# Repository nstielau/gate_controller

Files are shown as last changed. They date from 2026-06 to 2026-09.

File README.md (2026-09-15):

# Gate Controller

Secure, timed gate control using a Seeed Studio XIAO ESP32-S3 running
CircuitPython and a Firebase web app.

The [Drawbridge mobile app](https://drawbridge-45487.firebaseapp.com) uses Google
sign-in to send timed MQTT holds: 1m, 15m, 1h, 6h, or End hold. Connection
secrets stay in Firebase; each user sees their assigned gates. See the
[web app guide](firebase/README.md) for access administration, testing,
and deployment. Use `make web-test-unit` for quick checks, `make web-test`
for the full local suite, and `make web-deploy` to test and deploy Firebase.
`make web-test-mqtt` checks the live broker on a synthetic topic.

Per-device MQTT credentials are a planned hardening step. See the
[per-device credentials plan](docs/per-device-mqtt-credentials.md).
Administrators can manage roles and per-device OTA targets through the profile
menu's **Administration** view. Nick is the initial owner. See
[OTA operations](docs/ota-operations.md) for opt-in enrollment, GitHub releases,
USB recovery, and the required bench verification before field use.

The XIAO ESP32S3 CircuitPython app provides Wi-Fi provisioning, MQTT, and
connection/hold indicators. See [circuitpython/README.md](circuitpython/README.md)
for setup, deployment, and hardware verification. Host dependencies are
managed with `uv`; use `make setup`, `make test`, and `make deploy` from the
repository root.

Install the repository checks once, then let pre-commit run them on each commit:

```sh
make precommit-install
make precommit       # run against every tracked file
```

The hooks detect private keys and likely secrets, validate JSON/XML, catch
merge conflicts and whitespace errors, and run Ruff linting/formatting. Use
`make lint` for the Python-only Ruff check. Secret files such as `.env` and
`emqxsl-ca.crt` are ignored by Git and excluded from scanning.

The current bench firmware holds D10/GPIO9 LOW at startup. A hold message raises
D10 steadily for the requested duration. D2/GPIO3 blinks four times per second
while holding and is otherwise off. D0/GPIO1 indicates Wi-Fi; D1/GPIO2 indicates
MQTT readiness. The onboard LED pulses every two seconds to show the loop is
running. Each external LED needs its own 1 kΩ series resistor and ground return.
The temporary startup check flashes all three external LEDs three times.
D9 is unused. The diagrams below predate the four-LED assignment; see
[firmware LED wiring](circuitpython/README.md) for the current pin roles.
See the [connection guide](docs/xiao-breadboard.svg) and the
[170-hole mini breadboard layout](docs/xiao-breadboard.md), including the
Fritzing project and exact hole assignments. The transistor collector
LED is a disconnected bench load; the prospective LiftMaster eyes interface
has not been validated. Current firmware ignores legacy MQTT blink commands.
The installed wiring is documented in [this field photo](docs/wiring-installed.jpg).

The LiftMaster controller's EXIT terminal pair and its current yellow/green
wiring are shown below. Use this as a visual record of the installation; it
does not establish the terminal's electrical interface or ratings.

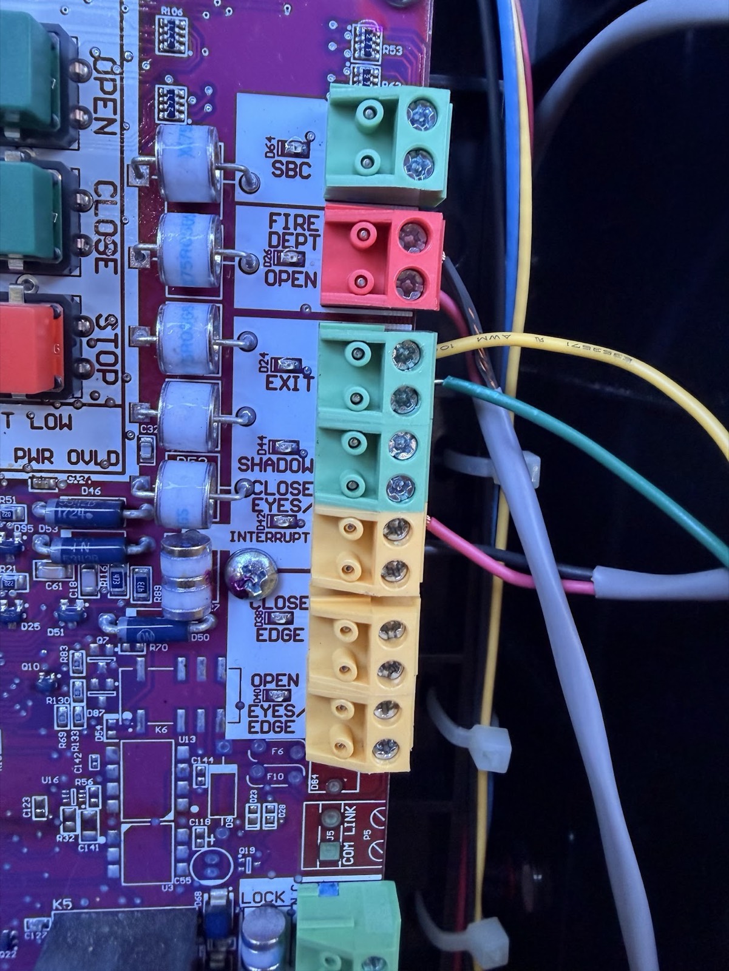
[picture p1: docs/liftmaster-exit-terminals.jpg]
LiftMaster EXIT terminal wiring


## Hardware

The current PCB is the [Drawbridge FeatherWing](hardware/featherwing/README.md),
50.8 × 22.86 mm, two layers, 1.6 mm thick. It fits above a Feather using underside
headers. J3 is a top-side 2.54 mm screw terminal for OUT_OC and GND, facing away
from USB. The transistor stage uses a 2N3904, 1 kΩ base resistor, and 100 kΩ
pulldown; each white/blue/green status LED has its own 1 kΩ resistor.

See [the generated BOM](hardware/featherwing/bom.csv) for exact parts and
[circuitpython/README.md](circuitpython/README.md) for the XIAO firmware wiring.
Older files at the root of `hardware/` are reference designs, not this board.

Commit all changes, then generate the fabrication package with `make featherwing-fab`.
The build requires a clean checkout; revisions use the first three HEAD characters,
and each ZIP records the full commit hash.
Use the freshly generated files in `artifacts/featherwing/`; the
[upload guide](hardware/featherwing/README.md#pcbway-upload) maps each file to its
PCBWay or Seeed upload field.

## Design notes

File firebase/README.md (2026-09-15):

# Drawbridge web app

Open [Drawbridge](https://drawbridge-45487.firebaseapp.com) and sign in with Google.
The `drawbridge.stielau.us` and `.web.app` aliases redirect to this canonical origin before initializing
authentication. Keep `web/origin.mjs` aligned with Google's OAuth redirect URI:
`https://drawbridge-45487.firebaseapp.com/__/auth/handler`. Firebase authorized
domains and Google OAuth redirect URIs are separate settings. Do not switch
`authDomain` to `.web.app` without first registering its callback with Google.
The mobile app offers **1 minute, 15 minutes, 60 minutes, 6 hours**, and
**End hold**. A six-hour hold asks for confirmation. Add it to your phone's
home screen for quick access.

The favicon uses `web/drawbridge-castle-128.png`, matching the header artwork.
Home-screen icons are checked-in exports in `web/icons/`; regenerate them with
`node tools/export_castle_icons.mjs` (requires the Playwright Chromium browser
installed by `make web-setup`). Regular builds only copy these files.

The centered loading indicator uses the original icon's pixels, with its bridge
rotating about the doorway hinge and suspension chains following the free edge.
`tools/build_loader_artwork.mjs` builds `web/drawbridge-loader.svg` from the
original icon and `web/drawbridge-loader-background.png` (an image-edited patch
visible only where the old bridge/chains were). Reduced-motion users see the
original still icon. Web builds regenerate, hash, and cache the loader asset.
`node tools/render_loader_gif.mjs` refreshes `artifacts/drawbridge-loader.gif`
with a complete four-second cycle at 50 fps and a live SVG preview at
`artifacts/drawbridge-loader.html`; this preview needs Playwright and ffmpeg.

To name a gate, select it and tap **Edit nickname**, enter a name, then tap
**Save nickname**. Names are shared with everyone assigned to that gate and
persist across visits. Any assigned user can rename an enabled gate. Names
must contain 1–80 characters; renaming does not send an MQTT command.

Only assigned users can control a gate. The browser receives gate IDs and
display names, never MQTT credentials or arbitrary broker/topic parameters.
The first assigned account is `nick.stielau@gmail.com`, for gate `b3640c`.

Administration has **Admins** and **Device Firmware** tabs and a refresh icon.
Firmware cards show the last reported app/base pair, separately from the assigned
target. Older boards show “Base not reported” until their USB bootstrap supports
independent reporting. See [OTA operations](../docs/ota-operations.md).

## Architecture and behavior

Firebase Hosting serves bundled HTML/JS/CSS. Google Authentication identifies
the user; reCAPTCHA Enterprise App Check protects all callable functions.
`listDevices` returns assigned, enabled gates. `holdGate` checks verified Google
sign-in, the current device allowlist, enabled state, exact topic, approved
duration, UUID request ID, and request age (60 seconds; 10 seconds of future
clock tolerance). CORS allows the two Drawbridge Hosting domains.

Accepted timed holds are counted server-side in each device record as
`holdCount` and shown as a small “holds issued” metric in the web app. End-hold
commands and uncertain deliveries do not increment the count.

Firestore transactions reserve commands before publishing, enforce a
three-second per-device cooldown, and prevent a repeated request ID from
publishing again. A changed payload with the same ID is rejected. Commands
are stored in `commands/<sha256(uid:requestId)>` with operator UID, device,
duration, timestamps, and `pending`, `accepted`, or `unknown` status. Keep these
records for audit; automated record deletion is not configured.

The function uses the existing EMQX broker over verified TLS on port 8883,
with the CA and credentials in Secret Manager. It publishes QoS 1 with
`retain=false`, using the existing firmware schema:

```json
{"version":1,"type":"hold_gate","duration_seconds":60,"command_id":"64-character-request-hash"}
```

Zero ends a hold. The XIAO starts timing when it receives the command. A new
command replaces the previous duration; it does not add to it.

**Accepted means MQTT PUBACK, not confirmation that the board received the
command or that the gate moved.** There is no physical gate-position feedback.
A disconnect, timeout, or ambiguous audit update reports uncertain delivery.
The app never queues offline commands or automatically retries a hold.
Request deduplication prevents repeated HTTP requests from publishing twice;
MQTT QoS 1 itself does not guarantee exactly-once hardware execution.

When a hold is accepted, Drawbridge stores its expected start and duration on
the gate record. The matching duration button displays a countdown and an
elapsed left-to-right color sweep. It survives refreshes and is shared with
other authorized users. It is an expected countdown only: direct MQTT commands,
lost board connectivity, or a command accepted by the broker but not delivered
to the board can make it disagree with physical gate state. An uncertain web
command clears the displayed expected hold rather than showing stale progress.

The app shell is cached with content-hashed assets and a content-based service
worker release. HTML and the service worker revalidate; hashed assets use
immutable caching. Updates offer a reload button. Authentication helpers,
API responses, external resources, and POST requests are never cached by the
service worker. An offline launch can display the shell, but sign-in and
commands still require connectivity. A first command after idle may take a
few seconds because functions scale to zero.

## Local setup and commands

Use Node/npm, Firebase CLI (tested with 15.30.0), gcloud, Java 21+, and the
repository's uv-managed Python environment. `make web-setup` installs a pinned
local Node 22 runtime, matching deployed functions, plus browser test binaries.
Keep both npm lockfiles committed. The UUID override patches a transitive
Google SDK dependency; review it with future SDK updates.

```sh
make setup
make web-setup
make web-build
make web-test-unit       # fast, offline validation + MQTT transport failure tests
make web-test-browser    # mobile Chromium and WebKit with a test gateway
make web-test-emulator   # actual Firestore transactions and deny-all client rules
make web-test           # all three
make web-test-mqtt      # live broker, three synthetic-topic cycles; no gate actuation
make web-test-live      # deployed OAuth redirect and unauthenticated API rejection
make web-deploy         # full web tests, then Functions + Hosting + rules
make web-status
```

The emulator target uses `demo-drawbridge` and refuses non-local Firestore
hosts. On macOS it checks Java via the Homebrew path; override
`JAVA_BIN=/path/to/java/bin` on other installations. These tests never publish
to the real gate. Existing `make test` and `make deploy` still test/deploy the
CircuitPython firmware independently.

The browser tests use a separate build in `artifacts/web-test`. Production
builds always use the real Firebase gateway and require both ignored public
config files. Never deploy the test build. Production output is `web/dist`.

### Public configuration on another checkout

Project: `drawbridge-45487`; region: `us-east1`; web app:
`1:498911170567:web:67d0d78cf97be687c85aa2`.

`.firebaserc` selects this project. Do not run `firebase init` over the existing
configuration. Copy `web/firebase-config.example.js` to
`web/firebase-config.js` and populate it from:

```sh
firebase apps:sdkconfig WEB 1:498911170567:web:67d0d78cf97be687c85aa2 --project drawbridge-45487
.venv/bin/python tools/firebase_cloud.py appcheck
```

The App Check helper reuses the Drawbridge reCAPTCHA key, registers the two
production domains, and writes `web/app-check-config.js`. Both configs contain
public identifiers, not authorization credentials, and are ignored locally.
No debug-token bypass is included in the production app.

### Access and device administration

Gate-access helpers use your gcloud login as `nick.stielau@gmail.com` and
project IAM. The profile dropdown also exposes **Administration** to server-verified
administrators. That view manages admin email assignments and per-device firmware
targets, separately from gate-control UID allowlists. `make admin-seed` initializes
Nick's protected owner record. All browser admin calls require verified Google
sign-in, App Check, and transactional role checks. See
[OTA operations](../docs/ota-operations.md) for release publishing, enrollment,
private artifact storage, and USB recovery.

```sh
make web-grant EMAIL=person@example.com DEVICE_ID=b3640c
make web-revoke EMAIL=person@example.com DEVICE_ID=b3640c
node_modules/.bin/node firebase/functions/admin.cjs disable nick.stielau@gmail.com b3640c
node_modules/.bin/node firebase/functions/admin.cjs enable nick.stielau@gmail.com b3640c
```

Grant reserves a Firebase user UID if that email has not signed in yet.
The user must still complete verified Google sign-in. Existing device access
lists are updated without replacing other users. Newly created device
documents default to enabled with the canonical command topic. Revoking
access or disabling a device blocks future commands; it does not cancel an
already-running hold. Sign in and select **Refresh access** after assignment.

Device documents live at `devices/<device-id>`:

```json
{
  "name": "Driveway gate",
  "enabled": true,
  "commandTopic": "gate/v1/devices/b3640c/command",
  "allowedUsers": ["firebase-auth-uid"]
}
```

Change the display name in the app with **Edit nickname**, or in the Firestore
console. The `renameGate` callable checks access transactionally and updates
only `name`; it cannot change device IDs, topics, permissions, or enabled state.
Access is by UID, not email.
Assign additional device IDs to different users with the same helper. This
release supports multiple devices on the existing broker; additional brokers
require server configuration and additional Secret Manager bindings.

### Secrets and deployment

```sh
make web-secrets
make web-deploy
```

The secret helper reads `MQTT_USERNAME` and `MQTT_PASSWORD` from ignored `.env`
and PEM data from ignored `emqxsl-ca.crt`. It uploads only changed values, without
printing them. Redeploy functions after rotation. Old secret versions remain;
disable superseded versions after confirming the new deployment works.

Runtime identity: `drawbridge-functions@drawbridge-45487.iam.gserviceaccount.com`.
It needs `roles/datastore.user` on the project and Secret Accessor on the three
MQTT secrets (the Firebase deploy command grants secret access). It does not
need project Editor. Functions use 256 MiB, zero minimum instances, two maximum
instances each, and a 30-second timeout. Function build images are cleaned up
after seven days. Blaze billing is enabled; no paid minimum instances are used.

## Verification and remaining manual checks

Automated coverage includes unauthenticated and non-Google rejection,
unassigned/disabled/missing devices, topic tampering, every duration, stale
requests, duplicate and concurrent requests, rate limiting, audit outcomes,
TLS options, timeout/error cleanup, mobile layout, sign-out, and offline
controls. The live MQTT smoke check verifies the real CA/credentials and
three publish/receive cycles on a unique `web-test-...` device topic.

Cached offline launch is automated in Chromium. The WebKit version of that
one test is explicitly skipped because Playwright's service-worker support
is Chromium-only; offline controls still run in both browsers. See
[Playwright service workers](https://playwright.dev/docs/service-workers).
Verify home-screen launch, Google redirect sign-in, and offline relaunch on
a real iPhone. Test a real hold only when gate actuation is intended, then use
End hold and check the board logs. Mock browser tests and synthetic MQTT
cycles do not prove a physical gate action.

For deployment checks, open the production app, confirm Google sign-in,
check that your assigned gate appears, and verify signed-out API requests
are rejected. First sign-in is an interactive step the CLI cannot complete
for you. The app deliberately does not claim a gate is open based solely on
broker acceptance.

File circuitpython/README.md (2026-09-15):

# XIAO ESP32S3 CircuitPython app

Wi-Fi provisioning, MQTT over verified TLS, and separate connection/hold
indicators. Targets CircuitPython 10.x; tested on 10.3.0.

| Output | Behavior |
| --- | --- |
| Onboard yellow LED | Running heartbeat: two 100 ms flashes, starting 250 ms apart, every 2 seconds (1.0.1). |
| D0 / GPIO1 external LED | Wi-Fi: 500 ms transitions while connecting; steady ON when connected. |
| D1 / GPIO2 external LED | MQTT: OFF without Wi-Fi; 500 ms transitions while connecting; steady ON after subscription. |
| D2 / GPIO3 external LED | Hold: OFF normally; four full blinks per second while D10 is HIGH. |
| D10 / GPIO9 transistor control | LOW at boot; HIGH only for the requested hold duration. |

D9 is reserved for optional OTA maintenance recovery. A hold command raises D10 steadily for its duration.
The D2 LED reports the commanded transistor state, not sensed gate position.
The temporary startup diagnostic flashes D0/D1/D2 together three times,
then releases the pins before normal operation. Its function and call are
marked for later removal.

Wire each of **D0, D1, D2 → its own 1 kΩ resistor → LED anode (+);
LED cathode (−) → XIAO GND**. D2/GPIO3 is a strapping pin; do not add a
pull-up or externally drive it during reset.
The [connection guide](../docs/xiao-breadboard.svg) predates this four-LED assignment.
D0 and D10 are board
labels: **D0 is GPIO1**, and **D10 is GPIO9**. The red charging LED is separate.

The onboard LED is active low; external LEDs are active high.
D2 uses 125 ms transitions, giving four complete on/off cycles per second.
All LED timers are independent of D10. Blocking Wi-Fi/TLS operations can briefly
pause blinking, especially during connection attempts.

## Setup and deployment

From the repository root, use **uv** (Python 3.11+):

```sh
make setup
make test
make deploy
```

Host dependencies are locked in `tools/requirements-dev.lock`. Refresh after
changing dependencies with:

```sh
uv pip compile tools/requirements-dev.txt -o tools/requirements-dev.lock
```

Put the downloaded CA at ignored `emqxsl-ca.crt` and credentials in ignored
`.env`:

```dotenv
MQTT_USERNAME=your-device-username
MQTT_PASSWORD='your-device-password'  # pragma: allowlist secret
```

Deployment copies the CA to `/certs/emqxsl-ca.crt` and renders only MQTT
username/password into device `settings.toml`, readable over USB. REST API
credentials stay on the host. The dotenv parser accepts literal quoted or
unquoted values; the last duplicate wins and process environment overrides
the file.

`make deploy` runs tests, preflights inputs, then copies changed app/library
files to `/Volumes/CIRCUITPY`, preserving unrelated files and settings.
Override with `CIRCUITPY=/path`. Filesystem writes normally trigger Python
autoreload; network recovery never deliberately hard-resets the board.

With missing settings, join the open `Gate-Setup-<chip suffix>` network and
visit `http://192.168.4.1`. The portal stores settings in NVM; deploy-time MQTT
credentials override saved credentials. Provisioned devices retry in station
mode after connection failures instead of reopening the portal.

## MQTT status

Default topics are `gate/v1/devices/<device-id>/command` and `/status`.
The ID is the lowercase chip suffix (`b3640c` for this board). The portal
can configure custom topics.

The device publishes retained `device_status` at connection and every ten
seconds with `boot_id`, `uptime_ms`, IP, and an `indicators` object containing
`wifi_connected`, `mqtt_connected` (both Wi-Fi and MQTT ready), `transistor_high`,
`wifi_led_on`, `mqtt_led_on`, `onboard_led_on`, `alive_edge_count`,
`hold_led_on`, and `hold_edge_count`.
Its last will reports `state: "offline"`.

The command schema is `{"version":1,"type":"hold_gate","duration_seconds":5,
"command_id":"unique-id"}`. Duration is 0–86400 seconds; zero cancels.
Commands are never retained, so a reboot cannot replay a timed gate action.
The firmware also rejects retained hold deliveries, including stale retained
messages left by older publishers.
Use `make hold DURATION=5` or `tools/mqtt_hold.py`. Invalid legacy blink
commands are rejected and cannot change either output.

## Verification

```sh
make test                   # offline regression suite
make test-hardware-smoke    # passive 20-second observation
make test-hardware          # passive 70-second observation
```

Host tests cover connection/hold LED independence, timed hold expiry, active-low polarity,
D0/D1/D2/D10 allocation and shutdown, legacy-command rejection, MiniMQTT handling,
configuration migration, portal parsing, publisher, and deployment behavior.

The live test requires a provisioned board connected over USB with working
Wi-Fi/MQTT. It waits up to 40 seconds for an online heartbeat, then checks
steady D0/D1 ON, advancing onboard heartbeat edge counts, and stable session logs. Hold activation should be tested
with `make hold DURATION=3` while watching the console. It fails on session/boot changes,
serial loss, missing heartbeats, or tracebacks. It never sends a command or
resets the board. The full run observes beyond the MQTT keepalive interval;
use it after firmware, timing, network, or library changes.

```sh
make test-hardware TEST_ARGS='--duration 120'
```

Raw logs and a JSON summary are saved to ignored `artifacts/indicators.*`.
These are software GPIO measurements; confirm physical light output visually.
Inactive-hold and disconnected behavior are covered by host tests; the live
indicator check does not activate the gate by itself.
The former MQTT command-cycle test does not apply to these automatic LEDs.

## Console

```sh
make console CONSOLE_WAIT=20
make console CONSOLE_WAIT=20 CONSOLE_ARGS=--reload
```

Default monitoring is passive; `--reload` intentionally restarts Python.
Use one serial reader at a time. With multiple boards, supply
`CONSOLE_ARGS='--port /dev/cu.usbmodem...'` or the live test's `--port` option.

The collector-powered LED in the diagram is a disconnected bench load.
The separate signal LEDs stay on the XIAO side. The prospective LiftMaster “eyes”
connection has not been established as a compatible gate-control interface.

## Opt-in OTA application updates

`drawbridge.py` contains the versioned application policy; `code.py` retains
networking and physical output leases. `boot.py`, the loader, libraries, and
the root recovery app are deployed over USB. OTA writes verified application
slots under `/ota/` and uses a trial boot before confirmation. Updates are
initially disabled. Two installations, hold deferral, and failure rollback have
passed on the bench; [the validation record](../docs/ota-bench-validation.md)
tracks remaining recovery and power-loss checks.
See [OTA operations](../docs/ota-operations.md) before enabling a device.
D9/GPIO8 is reserved as the active-low maintenance input during reset when
OTA is enabled on the XIAO. All other current pin roles are preserved.

The base and OTA app have independent versions. `lib/gate_base.py` defines the
USB bundle's `BASE_VERSION`; the selected application's `APP_VERSION` can move
forward independently. MQTT/Firebase report both, and Administration displays
the pair. Older boards show “Base not reported” until deliberately updated by
USB. Protected base commits require a version bump and change note; see the
OTA editing boundary in [AGENTS.md](../AGENTS.md).

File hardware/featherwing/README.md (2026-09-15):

# Drawbridge FeatherWing fabrication package

This is a revision-stamped prototype board for a Feather-compatible host,
including the Unexpected Maker FeatherS3[D] and Adafruit ESP32-S3 Reverse TFT
Feather. It provides the existing, proven 2N3904 transistor output unchanged:
J3 pin 1 is the switched output and J3 pin 2 is the shared ground. The Feather
module is not part of the assembly BOM.

Schematic and PCB signal names use portable Feather header labels:
`WIFI_D5`, `MQTT_D6`, `HOLD_D9`, and `CTRL_D11`. GPIO numbers differ between
Feather models and therefore are not part of these net names.

## PCBWay upload

The generated PCB is `drawbridge-featherwing.kicad_pcb` and the schematic is
`drawbridge-featherwing.kicad_sch`. Generate the fabrication package from the
repository root with:

```sh
make featherwing-fab
```

Every run regenerates the design from `generate.py`, runs ERC/DRC, and replaces
the **entire** `artifacts/featherwing/` directory with a complete release. Do not
keep manual edits or source files in that output directory. Old extracted ZIPs,
previews and reports disappear automatically. Other artifact folders are separate.
If a build fails, the last complete release remains available; its timestamp in
`manifest.json` identifies when it was built. Never upload after a failed build
assuming that the files reflect your latest source changes.

Each build requires a **clean Git checkout**, including staged, unstaged, and
untracked files anywhere in the repository. Commit changes before running the
build. Ignored files such as credentials and `artifacts/` do not block it.
There is no dirty-build override or generation counter.

The revision is exactly the first three characters of Git `HEAD`, for example
`abc`, with no suffix. It appears below the castle and in `manifest.json`.
Every ZIP contains `REV_abc.txt` with both `abc` and the **full commit hash**;
use the full hash to identify a commit unambiguously. Rebuilding the same commit
keeps the same revision. The build checks checkout cleanliness and HEAD again
before replacing the output.

Generation runs on a temporary snapshot of committed sources and leaves the
checkout unchanged. The freshly stamped native KiCad project is exported to
`artifacts/featherwing/design/` and included in the combined ZIP. Open that
project to inspect the current release; tracked native KiCad files are reference
snapshots and may carry an older revision. Incorporate edits into the generator,
commit them, then rebuild.

Prerequisites: KiCad 10 in `/Applications/KiCad`, `make setup`, and the repository's
Node/Playwright installation (`make web-setup`, then `npx playwright install chromium`
if Chromium is missing). Incorporate manual KiCad edits into `generate.py` before
rebuilding because the generator is the design source of record.

PCBWay uploads from `artifacts/featherwing/`:

| Upload field | File |
| --- | --- |
| Gerbers | `drawbridge-featherwing-gerbers.zip` |
| Parts list / BOM | `assembly-bom.xlsx` (PCBWay upload) |
| Centroid | `assembly-position.csv` |
| Assembly other files | `drawbridge-featherwing-assembly-other.zip` |
| Complete package for review | `drawbridge-featherwing-pcbway.zip` |

For Seeed Studio Fusion, upload `seeed-assembly-bom.csv`. It uses Seeed's
four-column `Designator`, `Manufacturer Part Number or Seeed SKU`, `Qty`, and
`Link` format and consolidates identical MPNs. All parts except J3 are selected from Seeed's Shenzhen Open Parts Library
(OPL); their links search the live OPL listing. J3 is Phoenix Contact 1725656
and uses its manufacturer link for external sourcing by Seeed (not verified
OPL stock). The BOM includes the two underside Feather headers, five resistors,
Q1, three LEDs, and J3. The Feather host is excluded. Check live availability when requesting a quote because OPL stock
changes independently of this repository.

The selected XKB headers have 2.54 mm pitch, 2.5 mm insulators, 3.0 mm solder
tails, and 6.0 mm mating pins. Seeed must install their bodies on the bottom of
the wing, with the 6.0 mm pins pointing down into the Feather's sockets. The
LEDs are a matching Everlight 3 mm family; observe the KiCad cathode/pad-1
orientation during assembly.

All three ZIPs are generated together and every member is byte-checked against
the corresponding loose file. Gerbers and drills are also available in `gerbers/`
and `drills/`. Each run refreshes `board.png`, `schematic.pdf`, `schematic.svg`,
`schematic.png`, `silkscreen.svg`, logo SVG/PNG, BOM, positions, `netlist.xml`,
`erc.rpt`, `drc.rpt`, and assembly notes. `manifest.json` records the build time
and SHA-256 for every loose file and ZIP (excluding the manifest itself).
The BOM is emitted as both `assembly-bom.xlsx` for PCBWay and `assembly-bom.csv`
for review. Both include an explicit `Tolerance` column: all five resistors
(R1–R5) have a tolerance of **5%**. R1/R3/R4/R5 are 1 kΩ Yageo
CFR-25JB-52-1K; R2 is 100 kΩ Yageo MFR50SJT-52-100K. Use 5% for the
PCBWay assembly specification; 1% is not required.

The isometric castle logo uses a 14 × 14 mm SVG canvas with 0.18 mm strokes.
The actual mark occupies about 12 × 12.5 mm on the USB end. The generator imports
`assets/drawbridge-silkscreen.svg` directly into F.Silkscreen. The 840-pixel PNG
is generated from that same SVG as a reference; no separate logo placement by
PCBWay is needed. For a bare-board order, only the Gerbers and drill files are
needed. For assembly, select through-hole assembly and ask PCBWay to
confirm the listed manufacturer part numbers and header availability. J3 is a
top-side screw terminal at the right-hand edge, with wire entry facing outward
away from the USB connector.

Recommended starting options are two layers, FR-4, 1.6 mm thickness, 1 oz
copper, green solder mask, white silkscreen, and lead-free HASL. These are
defaults for quoting, not a manufacturing release.

## Release checks

Run `make featherwing-check` before uploading; it performs the same complete
rebuild as `make featherwing-fab`. Offline package freshness/failure recovery
tests run with `.venv/bin/python -m unittest test_suite.test_featherwing_fab`
and are included in `make test`. Inspect
the Gerbers in PCBWay's viewer, especially the Feather header orientation,
mounting holes, J3 polarity, and the antenna keepout at the FeatherS3[D] end.

The gate-controller interface remains installation-specific. The transistor
stage is retained because it is the known-working circuit. J3 is populated with
[Phoenix Contact MPT 0,5/2-2,54, 1725656](https://www.phoenixcontact.com/us/products/1725656).
Viewed from above with USB left, the upper screw is GND (pin 2) and the lower
screw is OUT_OC (pin 1). Follow these labels when reconnecting existing wires.
The terminal has a 5.54 x 6.2 mm body, 8.5 mm installed height, and 2.54 mm
contact pitch. Use 20–26 AWG wire, strip 4.5 mm, and tighten to 0.12–0.15 N m
while supporting the terminal body. Provide cable strain relief.

The local `Drawbridge:ExitTerminal` footprint retains KiCad's Phoenix footprint
contacts and both 1.1 mm non-plated locating holes from the manufacturer's
drilling drawing, 2.54 mm toward the wire-entry side of the contact pins. It
uses a 0.25 mm body courtyard and omits silkscreen at the wire-entry edge. Do not omit
these holes or substitute a generic 2.54 mm header footprint. J3 is included in
all assembly BOMs and in the top-side position file. The headers remain on the
underside. The board outline is unchanged at 50.8 x 22.86 mm.

Routing uses horizontal, vertical, and 45-degree segments, with chamfers at
right-angle turns. Connected branches may still meet at right angles; these
are electrical junctions, not sharp bends in a continuous route. Copper/holes,
component courtyards, and silkscreen are checked on every fabrication build.
The terminal and cable are near the Feather's antenna end: RF performance and
assembled stack/enclosure clearance need checking with the actual host. DRC
does not establish either of those physical properties.

The Feather-compatible J1 (16-pin) and J2 (12-pin) stacking headers are
bottom-side assembly parts. Their XY pin coordinates are intentionally not
mirrored, preserving the Feather pin order when this board is placed on top of
the Feather host.

## Indicator LEDs

The 3 mm through-hole LEDs in the assembly BOM are assigned as follows:

| Reference | Function | Color |
| --- | --- | --- |
| D1 | Wi-Fi | Cool white |
| D2 | MQTT | Blue |
| D3 | Hold | Green |

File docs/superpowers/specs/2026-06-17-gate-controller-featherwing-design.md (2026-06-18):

# Gate Controller FeatherWing PCB Design

## Overview

A FeatherWing add-on board that replicates the existing Raspberry Pi gate controller circuit on the Adafruit Feather form factor. The board uses an NPN transistor to provide a dry-contact switch for a LiftMaster gate controller's "hold open" input, with a hardwired green LED for gate-active indication and a NeoPixel for firmware-controlled RGB status.

## Board Specifications

- **Form factor**: Adafruit FeatherWing (50.8 x 22.86mm, 2-layer)
- **Base template**: mignon-p/FeatherWing-template-KiCad (KiCad 5, auto-converts to KiCad 8)
- **Feather compatibility**: Board-agnostic; any Feather with GPIO will work. ESP32 HUZZAH recommended for WiFi.
- **Mounting**: 4x M2.5 holes at standard Feather positions
- **Connectors**: Standard 16+12 pin headers (from template) + 2-position screw terminal for gate wires

## Schematic

### Transistor Switch (dry contact output)

Pin A0 drives Q1 (2N3904 NPN) through a 1k base resistor. The collector connects to one screw terminal pin; the emitter and the other screw terminal pin connect to GND. When A0 goes HIGH, the transistor saturates and shorts the two screw terminal pins together, which the LiftMaster reads as "hold open."

```
A0 --+-- R1 (1k) -- Base -- Q1 (2N3904) -- Collector -- J3 pin 1
     |                        Emitter -- GND -- J3 pin 2
     +-- R2 (330) -- LED1 (Green) -- GND
```

### Gate-Active LED

LED1 (green, 0805 SMD) is hardwired to A0 through a 330 ohm resistor. It lights whenever the transistor is driven, providing a firmware-independent gate-active indicator.

### NeoPixel Status LED

A WS2812B on pin A1 provides firmware-controlled RGB status. A 330 ohm resistor on the data line prevents signal ringing. A 100nF bypass capacitor across VDD/VSS stabilizes the NeoPixel's power supply.

```
A1 -- R3 (330) -- DIN -- WS2812B -- DOUT (unused)
                  VDD -- 3V3
                  VSS -- GND
             C1 (100nF) across VDD/VSS
```

## Bill of Materials

| Ref | Part | Value | Package | Purpose |
|-----|---|---|---|---|
| Q1 | 2N3904 | NPN | TO-92 (THT) | Dry-contact switch |
| R1 | Resistor | 1k | 0805 (SMD) | Base current limiter (~2.3mA) |
| R2 | Resistor | 330 | 0805 (SMD) | Gate LED current limiter (~6mA) |
| R3 | Resistor | 330 | 0805 (SMD) | NeoPixel data line resistor |
| C1 | Capacitor | 100nF | 0805 (SMD) | NeoPixel bypass cap |
| LED1 | LED | Green | 0805 (SMD) | Hardwired gate-active indicator |
| LED2 | WS2812B | RGB | 5050 (SMD) | Firmware-controlled RGB status |
| J3 | Screw terminal | 2-pos 5.08mm | THT | LiftMaster connection |

## Pin Assignments

| Feather Pin | Function |
|---|---|
| A0 | Transistor base drive + gate LED |
| A1 | NeoPixel data in |
| 3V3 | NeoPixel power |
| GND | Common ground |

All other Feather pins are unused and available for future expansion.

## PCB Layout Notes

- Screw terminal J3 placed at board edge for easy wire access
- Q1 (TO-92) near the screw terminal to keep high-current traces short
- NeoPixel LED2 placed for top-side visibility
- Gate LED LED1 placed near NeoPixel for a clean indicator cluster
- SMD components (resistors, capacitor, LEDs) on top side
- Through-hole components (Q1, J3, pin headers) require bottom-side soldering

## Design Decisions

- **2N3904 over MOSFET**: Matches the existing working circuit. The dry-contact load is milliamps at low voltage, well within the 2N3904's 200mA/40V rating.
- **Hardwired LED + NeoPixel**: The green LED works without firmware (debug/failsafe). The NeoPixel adds rich status feedback under firmware control.
- **0805 SMD for passives**: Good balance of hand-solderability and board space savings.
- **5.08mm screw terminal**: Standard pitch for field wiring, easy to connect/disconnect without tools beyond a small screwdriver.
- **A0 for transistor**: Easily identifiable pin across all Feather boards.

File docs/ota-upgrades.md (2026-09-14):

# Future plan: safe OTA application upgrades

Status: original design proposal, retained for context. The first implementation
now exists; see [OTA operations](ota-operations.md) for the actual two-slot
storage, authenticated download endpoint, administrator UI, commands, and
outstanding physical verification. The original rename-based algorithm below
was replaced by two application slots and checksummed journals. Channel-wide
promotion and signed manifests remain future work.

## Recommendation

Use a small, stable `code.py` as the safety shell and update one self-contained
`drawbridge.py` application file over the air. GitHub Releases should be the
human-visible source of released artifacts. A device-authenticated Firebase
HTTP endpoint should decide which release a particular controller should run,
and the released file should be mirrored under an immutable, versioned object
name in Google Cloud Storage.

This first version should deliberately exclude OTA changes to `boot.py`,
`code.py`, CircuitPython itself, certificates, and `.mpy` libraries. Those
components define the updater and its recovery path and should continue to use
the tested USB deployment process. A later package updater can be considered
after the single-file design has accumulated field experience.

## Proposed firmware split

### `boot.py`: filesystem ownership

CircuitPython normally gives the USB host write access to `CIRCUITPY`, which
prevents application code from safely replacing its own files. A future
`boot.py` would make the filesystem writable by CircuitPython during normal
field operation. CircuitPython documents that filesystem ownership must be
chosen at boot; disabling concurrent-write protection risks corruption
([storage documentation](https://docs.circuitpython.org/en/stable/shared-bindings/storage/)).

There must also be an explicit physical maintenance mode that leaves the drive
writable by the USB host for recovery and `make deploy`. A candidate is a
normally unused pin held low during reset, but its board mapping and strapping
behavior must be checked on both supported controllers before choosing it. The
maintenance path must be tested before enabling OTA. Do not rely on simultaneous
host/device writes or `disable_concurrent_write_protection=True`.

### `code.py`: stable bootstrap and safety shell

`code.py` would remain USB-managed and own:

- immediate initialization of D10 and all indicators to LOW;
- configuration/NVM migration and captive-portal provisioning;
- Wi-Fi, TLS, MQTT connection and reconnect behavior;
- the bounded physical output lease for D10;
- status publication and fail-safe cleanup after any application exception;
- firmware-manifest checks, streaming download, verification, activation,
  health confirmation, and rollback;
- the narrow API passed to `drawbridge.py`.

The downloaded application must not receive a raw GPIO object for D10. It may
request a bounded hold lease, and `code.py` validates the requested duration,
owns the monotonic deadline, drives the transistor, and forces it LOW on exit.
This keeps the physical safety behavior in the component that OTA cannot
replace.

### `drawbridge.py`: replaceable application

The first refactor should combine the current app-specific behavior from
`gate_hold.py`, `gate_indicators.py`, and the relevant parts of `code.py` into
one ordinary Python source file. Keeping the OTA unit to one file avoids a
partially installed set of modules.

The interface should be small and versioned. One possible shape is:

```python
APP_VERSION = "1.0.0"
APP_API_VERSION = 1

def create_app(platform): ...
# app.on_message(topic, payload, retained, now)
# app.tick(now)
# app.status_fields(now)
```

`platform` would expose bounded operations such as `request_hold(seconds,
command_id)` and logical indicator setters. It would not expose credentials,
filesystem mutation, arbitrary MQTT publication, or direct access to D10.
The initial split must be behavior-preserving and deployed by USB before any
OTA checks are enabled.

## Release and control plane

### Release production

A release should start from a clean, tagged commit such as
`firmware-v1.2.0`. CI would run the full offline firmware suite and build these
release assets:

- `drawbridge.py`;
- `manifest.json`;
- an optional human-readable change log.

The manifest should contain only fixed, validated fields:

```json
{
  "schema": 1,
  "app_version": "1.2.0",
  "app_api_version": 1,
  "minimum_bootstrap_version": "1.0.0",
  "circuitpython_major": 10,
  "supported_board_ids": ["seeed_xiao_esp32_s3_sense"],
  "size": 28417,
  "sha256": "...",
  "artifact_object": "firmware/1.2.0/<sha256>/drawbridge.py",
  "git_commit": "...",
  "released_at": "..."
}
```

CI should attach the file and manifest to a GitHub Release, then copy the exact
bytes to a create-only Cloud Storage object containing both the semantic
version and SHA-256 in its path. GitHub's release-asset API can serve public
assets but clients must handle either a direct response or redirect
([GitHub release asset documentation](https://docs.github.com/en/rest/releases/assets)).
The Google mirror is recommended for the device so the constrained client has
one tested TLS and redirect behavior. It also prevents a normal web deployment
from deleting historical firmware assets in `web/dist`.

Neither artifact location may contain Wi-Fi, MQTT, Firebase, or signing
secrets. Release automation must refuse to overwrite an existing version or
digest and must verify the GitHub and Google copies have identical SHA-256
values.

### Firebase records

Server-owned Firestore records could use this shape:

- `firmwareReleases/<version>`: approved manifest fields, immutable object
  location, rollout state, and release sequence;
- `devices/<device-id>.firmwareChannel`: normally `stable`, optionally
  `canary`;
- `devices/<device-id>.firmwareTarget`: optional per-device override;
- `devices/<device-id>.reportedFirmware`: last app/bootstrap version and
  update result reported by the device;
- `devices/<device-id>.otaCredentialHash`: hash of a random, device-specific
  OTA credential.

The browser should never write these fields directly. Existing deny-all client
Firestore rules should remain in place. Administration should use local IAM
tools or a tightly authorized admin function.

### Device API

CircuitPython should use a small ordinary HTTPS API rather than implementing
the Firebase callable protocol:

- `GET /device-api/v1/firmware` returns the selected manifest or `204`;
- `POST /device-api/v1/firmware/report` records download, activation, success,
  or rollback outcomes.

Requests should carry the stable device ID and a random per-device bearer token
in headers, never in a URL. The backend stores only a slow or keyed hash of the
token, rejects disabled devices, bounds request sizes, rate-limits checks, and
returns only server-approved manifests. A controller must not be allowed to
supply an arbitrary artifact URL. App Check is designed for supported Firebase
clients and is not a substitute for explicit microcontroller authentication.

The OTA token will be recoverable by someone with physical USB access, as the
MQTT credential is today. Per-device tokens limit that exposure to one device
and can be revoked independently. The token should not authorize gate commands,
user data, Firestore access, or another controller's firmware record.

## On-device update algorithm

The updater should check after Wi-Fi and MQTT have been healthy for a short
jittered interval, then approximately every six hours with jitter. Network
errors use exponential backoff capped at 24 hours and never reset the board.
The current application continues running after a failed check.

An update is permitted only when:

- D10 is LOW and no hold lease is active;
- Wi-Fi and MQTT are healthy;
- no previous trial or rollback is unresolved;
- the manifest schema, app API, board ID, CircuitPython major, and minimum
  bootstrap version match;
- the target release sequence is newer than the last applied deployment
  sequence, or the backend has issued an explicit newer rollback deployment;
- the declared size is within a bootstrap constant and free space can hold the
  active file, backup, staged file, and a safety margin.

Use a release/deployment sequence separate from the semantic app version. To
roll back to older application bytes, publish a new deployment sequence that
points to the older approved digest. This prevents accidental replay while
allowing deliberate rollback without a general `allowDowngrade` switch.

Download with a small fixed-size buffer into `drawbridge.new`; never load the
whole response into RAM. The Adafruit requests API supports streamed response
content and requires the response to be closed
([requests documentation](https://docs.circuitpython.org/projects/requests/en/stable/api.html)).
While downloading, continue servicing the physical output deadline, indicators,
and MQTT often enough to avoid turning a small update into a long network stall.
Reject redirects outside an allowlisted Google artifact origin, incorrect
content length, oversized bodies, timeouts, short reads, and digest mismatch.

After closing and flushing the staged file:

1. Compute SHA-256 locally and compare it with the authenticated manifest.
2. Write a pending-update marker using temporary-file-plus-rename.
3. Remove only a previously confirmed backup.
4. Rename `drawbridge.py` to `drawbridge.bak`.
5. Rename `drawbridge.new` to `drawbridge.py`.
6. Reload through `supervisor.reload()`.

At startup, `code.py` reconciles every possible interrupted state before
importing the application. If the active file is missing, it restores the
backup. If the new file cannot import, has the wrong API, throws during startup,
or resets repeatedly before health confirmation, it restores the backup and
reloads. Stale `.new` files are never executed.

The trial becomes healthy only after import succeeds, MQTT subscription is
restored, outputs remain serviceable, and the main loop runs for at least 60
seconds. Only then should the bootstrap record the installed deployment,
remove the pending marker, and eventually delete the backup. Update state needs
power-loss-safe storage; reserve and version a distinct NVM region only after
confirming capacity alongside the existing 512-byte configuration record.
Otherwise use two checksummed state files with alternating generations.

TLS plus SHA-256 means the authenticated Firebase response chooses the trusted
digest and the download is checked against it. It does not protect against a
compromised Firebase control plane. A later hardening step may sign manifests
offline and embed a public verification key in `code.py`, after confirming a
small, audited signature verifier works within CircuitPython memory limits.
Do not use one fleet-wide HMAC secret as a substitute.

## Operational behavior

Add app and bootstrap versions plus a bounded update status to the existing
retained MQTT status payload and `GATE_LOG`. Useful states are `idle`,
`available`, `deferred_hold_active`, `downloading`, `trial`, `current`, and
`rolled_back`, with an error category rather than raw exception data. Never log
the OTA token, signed URL query, Wi-Fi password, or MQTT credentials.

An admin workflow should eventually provide commands similar to:

```text
make firmware-release VERSION=1.2.0
make firmware-target DEVICE_ID=b3640c VERSION=1.2.0
make firmware-channel CHANNEL=canary VERSION=1.2.0
make firmware-status DEVICE_ID=b3640c
```

Release promotion should proceed from a USB-connected bench device, to one
canary controller, and then to `stable`. A target change must be reversible,
audited, and independent of user gate access. Updates should never be queued as
gate commands, and a restart must not replay an MQTT hold.

## Test plan

Host tests should model the updater as a state machine with fake network,
filesystem, clock, and output lease. Inject a simulated power loss before and
after every write, close, marker update, rename, import, and health transition.
At minimum, cover:

- exact manifest validation, compatibility bounds, size, and SHA-256;
- rejected unknown origins, traversal paths, malformed JSON, and oversized
  responses;
- storage-full, short-read, timeout, TLS, redirect, and hash failures;
- deferral for active holds and continued LOW output during bootstrap failures;
- new-app syntax/import/runtime failures and automatic backup restoration;
- interrupted activation with every combination of active, backup, staged,
  and pending files;
- replay prevention, explicit rollback deployment, backoff, and status redaction;
- an unreviewed `drawbridge.py` never reaching a release record.

Firebase emulator tests should cover device-token authentication, token
revocation, disabled devices, per-device/channel targeting, compatibility
selection, immutable release records, rate limits, and report validation. The
device endpoints use IAM-backed server access; Firestore client rules remain
deny-all.

Before field rollout, use a non-gate bench controller and test real HTTPS
streaming, SHA-256 memory use, filesystem ownership, host maintenance mode,
full-disk behavior, power removal during each activation step, bad Python
syntax, repeated crashes, recovery over USB, and a successful rollback. Then
run the existing passive hardware test plus a deliberate short hold. Hardware
evidence must confirm D10 stays LOW throughout update and recovery except for
that explicit hold.

## Delivery phases

1. **Behavior-preserving split:** create `code.py`/`drawbridge.py` boundaries,
   keep OTA disabled, and prove current MQTT, timing, indicators, provisioning,
   and USB deployment are unchanged.
2. **Recovery foundation:** add and verify `boot.py` ownership plus physical
   maintenance mode, staged file handling, trial health, and rollback using
   local test files only.
3. **Release pipeline:** build reproducible single-file artifacts, GitHub
   Releases, immutable Google mirrors, manifests, and secret scanning.
4. **Firebase control plane:** add device OTA credentials, release/target
   records, ordinary HTTPS endpoints, emulator coverage, audit records, and
   admin commands.
5. **Bench OTA:** enable checks only for a dedicated canary device and complete
   power-loss and failure-injection tests.
6. **Field canary and stable rollout:** promote one controller, observe it for
   at least a week, exercise rollback, then enable the stable channel.

The first implementation milestone should stop after phase 1 for review. The
filesystem and rollback work changes the device's recovery model and warrants a
separate, explicitly tested change before any network-delivered file can run.

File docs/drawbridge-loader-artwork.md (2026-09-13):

# Drawbridge loader artwork

The loader reuses `web/drawbridge-castle-128.png` without repainting the castle.
The original bridge is clipped from that image and animated using an affine
projection about its fixed hinge. Chain endpoints follow the moving edge.
Only a small masked area behind the original bridge/chains uses new pixels,
from `web/drawbridge-loader-background.png`. The rest stays the original image.

The background patch was prepared using the built-in image generation/editing
tool, then resized to the original 128-pixel canvas for use in the SVG. The
generated image's outer background is never used. The original icon remains
unchanged, and reduced-motion mode shows that unmodified original.

Final image-edit prompt:

> Use case: precise-object-edit. Edit target is the attached 128x128 pixel-art castle app icon. Create a clean background layer for animating its existing wooden drawbridge. REMOVE ONLY the movable brown wooden drawbridge across the center doorway, and its two diagonal suspension chains. Fill the tiny exposed region with the existing stone threshold/doorway behind it and blue moat beneath it. Keep the fixed arched doorway and inner vertical wooden door. Preserve EVERYTHING else exactly: original pixel clusters, low-resolution detail, original proportions, original 128x128 coordinate framing, tower silhouettes and positions, wall textures, grass, ground, water, light, palette, camera and margins. This must look like the same literal source icon with only bridge and suspension chains erased and inpainted. Do not upscale into new detail or redesign the castle. Output a single square image with original transparent margins if possible. No grid or checkerboard pattern. No text. Intended output is a background patch used only behind the original moving bridge; matching source pixel coordinate alignment is essential.

Rebuild the SVG with `node tools/build_loader_artwork.mjs` (also runs during
`make web-build`). Rebuild the GIF preview with `node tools/render_loader_gif.mjs`.
The renderer embeds the same SVG used by the app and samples a full cycle at
fixed timestamps. It captures at 60 fps and exports a four-second GIF at 50 fps
(an exact 20 ms frame interval), with a generated palette to preserve the colors.
It also writes a live SVG HTML preview beside the GIF for native browser playback.

The deck uses an explicit scale/shear animation in coordinates aligned to the
hinge. This avoids CSS matrix decomposition flips when the deck passes edge-on.
The 120 animation intervals follow a cosine motion profile, slowing smoothly
at both endpoints. Only the moving deck texture is filtered for subpixel motion;
the fixed castle retains its original pixel rendering.

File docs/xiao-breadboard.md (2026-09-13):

# XIAO on a 170-hole mini breadboard

Open [the Fritzing project](xiao-breadboard.fzz) in **Breadboard** view.
[Rendered preview](xiao-mini-breadboard.svg) · [Circuit connection guide](xiao-breadboard.svg).

This layout assumes a standard **170-hole, 17 × 10 mini breadboard without
power rails**, with 2.54 mm hole spacing. USB faces left, the XIAO straddles the
center gap, and both LEDs and the transistor sit to its right. It uses nine
insulated jumpers. No separate screw-terminal block is needed for this bench circuit.

The drawing is rotated relative to some breadboards: numbers 1–17 run left
to right; A–E are above the center gap, F–J below. Each numbered group A–E
is connected internally, as is F–J. The two halves are separate.
If your board is unmarked, count from the left/top in the preview.
**Hole D0 is not the XIAO pin named D0.**

## Seat the components

Fit the resistors and short jumpers before seating the XIAO. Its headers must
be soldered. Leave USB pointing off the left edge so the cable stays accessible.
Bend component leads to the listed hole spacing; insert one lead per hole.

| Part | Holes | Notes |
| --- | --- | --- |
| XIAO upper header | C1–C7 | Left → right: 5V, GND, 3V3, D10, D9, D8, D7 |
| XIAO lower header | G1–G7 | Left → right: D0, D1, D2, D3, D4, D5, D6 |
| R1, 1 kΩ | A4 → A9 | D10 to transistor base; 12.7 mm lead spacing |
| Q1, 2N3904 | E10 / E11 / E12 | Emitter / base / collector; verify your actual part's datasheet |
| R3, 100 kΩ | D9 → H9 | Base pulldown; 15.24 mm lead spacing |
| R2, 1 kΩ | D14 → H14 | Red bench LED current limit; 15.24 mm lead spacing |
| Red LED1 | Cathode E13; anode E14 | Steady when the transistor conducts |
| R4, 1 kΩ | D17 → H17 | Green hold LED current limit; 15.24 mm lead spacing |
| Green LED2 | Cathode E16; anode E17 | Blinks while D10 is HIGH; otherwise off |

The cathode is usually the shorter LED lead and the flat side of the lens.
Check polarity before cutting leads. The transistor illustration uses E–B–C
from left to right; do not assume that order for a different transistor.

## Add the nine jumpers

| Color | From | To | Connection |
| --- | --- | --- | --- |
| Orange | B9 | A11 | R1 output / pulldown to Q1 base |
| Black | B2 | A10 | XIAO GND to Q1 emitter row |
| Black | D10 | F10 | Carry ground across the center gap |
| Black | I9 | I10 | Pulldown return to ground |
| Black | J10 | J16 | Ground to hold LED return row |
| Black | F16 | D16 | Ground across the gap to the green LED cathode |
| Orange | A12 | A13 | Q1 collector to red LED cathode |
| Red | B3 | I14 | 3V3 to the red LED's resistor |
| Green | G1 | I17 | XIAO D0 to the green LED's resistor |

Use insulated jumper wire for routes that cross other leads. Crossings in
the drawing are not junctions; only the endpoint holes and breadboard's
internal strips connect. All power and ground connections use terminal rows.

## What to expect

Current firmware keeps **D10/GPIO9** and the green **D0/GPIO1** indicator LOW
until a hold command arrives. During the hold, D10 is HIGH and the green
indicator blinks four times per second; the red bench LED is on.
The onboard LED blinks until Wi-Fi and MQTT connect, then stays ON. D9 is unused.
The green LED reports the transistor output command, not sensed gate position.
Pin mapping: [Seeed's XIAO ESP32-S3 reference](https://wiki.seeedstudio.com/xiao_esp32s3_getting_started/).

The red LED and 3V3 branch are a bench load with the gate disconnected.
This drawing does not specify wiring to the LiftMaster monitored “eyes” input.

## Regenerate and verify

From the repository root, with Fritzing installed at `/Applications/Fritzing.app`:

```sh
make fritzing          # generate FZZ and validate connections/placement
make fritzing-preview  # also render the actual Fritzing breadboard view
```

The generator uses uv with pinned `svgelements`. The FZZ embeds its required
custom parts; there is no separate part-install step. It uses the bundled
GOKUX XIAO contribution, corrects its header spacing for seating, and normalizes
the core mini-board artwork to 2.54 mm pitch. The original FZPZ stays intact.
The schematic and PCB views are not laid out.

Validation checks eight distinct nets, used and unused XIAO pins, all fourteen
header positions, component lead alignment, and no duplicate occupied holes.
The preview is exported by Fritzing itself to catch asset and wire-rendering
errors. This is drawing validation, not an electrical measurement of an
assembled breadboard. Export diagnostics are in ignored
`artifacts/fritzing-mini/export.log`.

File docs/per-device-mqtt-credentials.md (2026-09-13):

# Future plan: per-device MQTT credentials

The current system uses one MQTT username and password for the XIAO and the
Firebase callable function. This is adequate for the first gate, but a leaked
device file would expose the shared account. The next security improvement is
to issue a separate broker identity for every device.

## Proposed design

1. Give each device a stable ID, such as `b3640c` (the XIAO chip suffix).
2. During enrollment, generate a random password and create an EMQX built-in
   authentication user named `xiao-b3640c`.
3. Add least-privilege authorization rules for that identity:
   - Subscribe to `gate/v1/devices/b3640c/command`.
   - Publish to `gate/v1/devices/b3640c/status`.
   - Deny unrelated topics and administrative operations.
4. Write the resulting username/password to the device's `settings.toml` over
   USB. Keep the broker CA on the device for verified TLS.
5. Store the enrollment record and a credential version in Firestore. Keep the
   EMQX deployment API App Secret only in Firebase Secret Manager.

EMQX provides HTTP API operations for users in its built-in password database.
The likely v5 endpoint is
`/api/v5/authentication/password_based%3Abuilt_in_database/users`; the exact
path and permissions must be confirmed against the deployment before coding.

## Enrollment and rotation

Enrollment should be an administrator-only Firebase operation. It should
validate the device ID, create the EMQX user, create its topic ACL, and return
the credentials only once for immediate USB provisioning. Re-enrollment should
disable the previous account before issuing a replacement. Lost or serviced
hardware should be revocable without changing other gates.

The browser must never call EMQX directly or receive the deployment App
Secret. Firebase Secret Manager should hold the EMQX API credentials, and the
callable function should log only the device ID and operation result, never a
password.

## Prerequisites and checks

- Confirm whether this deployment plan exposes the user and authorization API;
  EMQX Serverless has fewer customization options than Dedicated deployments.
- Create a narrowly scoped EMQX deployment API key if the plan supports it.
- Test create, ACL, connect, publish, subscribe, revoke, and rotate operations
  on a synthetic device topic before touching the gate.
- Update firmware provisioning and `make deploy` to select credentials by
  device ID, while retaining a safe migration path from the shared account.

Until these checks are complete, keep the existing shared account and rotate
it if the board or its USB-readable settings are exposed.

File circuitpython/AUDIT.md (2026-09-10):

# Implementation audit

The original MQTT failure was reproduced against MiniMQTT 8.1.0: the app
called `loop(timeout=0.02)` while the client socket timeout was one second.
MiniMQTT raised `ValueError`; the old broad reconnect handler treated that as a
network failure, repeatedly reconnecting and replaying the retained command.
The app also reset the microcontroller on connection errors, which explained
USB disconnect warnings.

The current implementation uses a small `GateMQTT` adapter for short idle
polls while retaining longer TLS and packet-read deadlines. `ValueError` is no
longer classified as a network failure, network recovery does not reset the
board, MQTT publishing is outside the receive callback, and duplicate delivery
of the same command ID does not restart the blink timer. The publisher uses
native TLS, QoS 1, and waits for PUBACK before reporting broker success.

The host suite tests the real pinned MiniMQTT package, fragmented packets,
command validation and timing, NVM migration, fragmented portal requests,
publisher acknowledgments, and content-based deployment updates. The hardware
runner correlates unique command IDs with four LED GPIO-edge logs, checks
alternation and timing, detects boot/session loss, and observes heartbeats
after the command cycles.

Use `make test-hardware-smoke` for one 300 ms command and a short 15-second
stability check while iterating. Use the default `make test-hardware` as the
release check: three alternating 2000/300 ms cycles followed by 70 seconds of
stability. Both tests leave their final command retained; the smoke test is a
fast feedback tool and does not replace the full check before hardware changes
are considered complete.

The edge measurements are software writes to `board.LED`, not optical
measurements. They establish firmware scheduling and session stability for the
tested window; an external sensor is needed to validate emitted light timing.

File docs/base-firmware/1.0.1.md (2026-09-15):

# Base firmware 1.0.1

This USB-managed base adds independent base/app version reporting to MQTT,
Firebase and application-ready logs. It includes the bench fixes for
CircuitPython bytearray slicing, explicit Google TLS roots, and string-valued
OTA enable settings. The reported base version identifies code.py, boot.py,
libraries and public certificates as a bundle, not the CircuitPython interpreter.

Install deliberately by USB in D9 maintenance mode. OTA updates still replace
only a verified application slot and cannot install this base. Preserve device
settings, credentials, NVM and confirmed app journals. Follow the recovery and
bench checklist in ../ota-operations.md; this change has host validation but
has not been installed or physically validated on the board yet.

Application API 1 and the existing 1.0.0 minimum-bootstrap contract are unchanged.
Older applications and releases remain compatible. Older boards that omit a
base version appear as “not reported” in Administration.

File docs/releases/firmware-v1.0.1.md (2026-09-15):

# Firmware 1.0.1

The onboard LED now gives two quick flashes every two seconds: 100 ms on,
150 ms off, 100 ms on, then off for the rest of the cycle. This repeating
pattern makes an installed 1.0.1 application easy to recognize. It uses the
existing nonblocking timer and active-low output handling.

Wi-Fi, MQTT and hold indicators retain their existing meanings. Gate command
validation, transistor output and hold deadlines are unchanged. The OTA asset
is only `drawbridge.py`, using application API 1 and bootstrap API 1.0.0.

After the release is imported, open **Administration**, select **1.0.1** for the
enrolled board and choose **Assign release**. The board checks on its existing
schedule (60–315 seconds after startup, then every six hours plus jitter);
assignment does not force an immediate check. Active holds defer the update.
After downloading, the application runs as a trial and confirms after 60
seconds of healthy MQTT connectivity. Check the reported version/state as
well as the new onboard flash pattern.

This release is intended for the already provisioned bench board. The bootstrap
fixes and remaining recovery/power-loss checks are tracked in
`docs/ota-bench-validation.md` in the working repository; publishing this
application does not update the USB-managed bootstrap or establish field
qualification.

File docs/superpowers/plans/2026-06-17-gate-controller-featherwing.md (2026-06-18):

# Gate Controller FeatherWing PCB Implementation Plan

> **For agentic workers:** REQUIRED SUB-SKILL: Use superpowers:subagent-driven-development (recommended) or superpowers:executing-plans to implement this plan task-by-task. Steps use checkbox (`- [ ]`) syntax for tracking.

**Goal:** Build a KiCad FeatherWing PCB that uses an NPN transistor to switch a dry contact for a LiftMaster gate controller, with a hardwired green LED and a NeoPixel for status.

**Architecture:** Edit the existing KiCad 5 schematic to add 8 components (Q1, R1, R2, R3, C1, LED1, LED2/WS2812B, J3) with their footprint assignments. Wiring and PCB layout are done interactively in KiCad 8 (which auto-converts KiCad 5 files on open). The schematic drives the PCB via KiCad's "Update PCB from Schematic" workflow.

**Tech Stack:** KiCad 8 (reading KiCad 5 project files), standard KiCad symbol/footprint libraries

**Spec:** `docs/superpowers/specs/2026-06-17-gate-controller-featherwing-design.md`

---

### Task 1: Add circuit components to schematic

**Files:**
- Modify: `hardware/gate-controller.sch`

This task adds all 8 circuit components plus power symbols to the schematic file. Components are placed in the left half of the schematic sheet (x=1500–6500, y=1200–5500), away from the existing Feather header symbols at x=8350+. No wires are added — wiring is done in Task 3 using KiCad's GUI, which is more reliable than hand-editing wire coordinates.

- [ ] **Step 1: Add component blocks to the schematic**

Insert the following content into `hardware/gate-controller.sch` immediately BEFORE the final `$EndSCHEMATC` line:

```
Wire Notes Line
	1500 1200 6500 1200
Wire Notes Line
	6500 1200 6500 5500
Wire Notes Line
	6500 5500 1500 5500
Wire Notes Line
	1500 5500 1500 1200
Text Notes 1600 1400 0    100  ~ 20
Gate Controller Circuit
$Comp
L Device:R R1
U 1 1 6651A002
P 3200 2000
F 0 "R1" V 3100 2000 50  0000 C CNN
F 1 "1k" V 3300 2000 50  0000 C CNN
F 2 "Resistor_SMD:R_0805_2012Metric" H 3200 2000 50  0001 C CNN
F 3 "~" H 3200 2000 50  0001 C CNN
	1    3200 2000
	0    1    1    0   
$EndComp
$Comp
L Transistor_BJT:2N3904 Q1
U 1 1 6651A001
P 4200 2000
F 0 "Q1" H 4391 2046 50  0000 L CNN
F 1 "2N3904" H 4391 1955 50  0000 L CNN
F 2 "Package_TO_SOT_THT:TO-92_Inline" H 4400 1925 50  0001 L CIN
F 3 "~" H 4200 2000 50  0001 L CNN
	1    4200 2000
	1    0    0    -1  
$EndComp
$Comp
L Connector:Screw_Terminal_01x02 J3
U 1 1 6651A008
P 5800 1700
F 0 "J3" H 5880 1692 50  0000 L CNN
F 1 "Gate_Output" H 5880 1601 50  0000 L CNN
F 2 "TerminalBlock:TerminalBlock_bornier-2_P5.08mm" H 5800 1700 50  0001 C CNN
F 3 "~" H 5800 1700 50  0001 C CNN
	1    5800 1700
	1    0    0    -1  
$EndComp
$Comp
L Device:R R2
U 1 1 6651A003
P 2200 3200
F 0 "R2" H 2270 3246 50  0000 L CNN
F 1 "330" H 2270 3155 50  0000 L CNN
F 2 "Resistor_SMD:R_0805_2012Metric" H 2200 3200 50  0001 C CNN
F 3 "~" H 2200 3200 50  0001 C CNN
	1    2200 3200
	1    0    0    -1  
$EndComp
$Comp
L Device:LED LED1
U 1 1 6651A006
P 2200 3800
F 0 "LED1" H 2193 4017 50  0000 C CNN
F 1 "Green" H 2193 3926 50  0000 C CNN
F 2 "LED_SMD:LED_0805_2012Metric" H 2200 3800 50  0001 C CNN
F 3 "~" H 2200 3800 50  0001 C CNN
	1    2200 3800
	-1   0    0    1   
$EndComp
$Comp
L Device:R R3
U 1 1 6651A004
P 3200 4600
F 0 "R3" V 3100 4600 50  0000 C CNN
F 1 "330" V 3300 4600 50  0000 C CNN
F 2 "Resistor_SMD:R_0805_2012Metric" H 3200 4600 50  0001 C CNN
F 3 "~" H 3200 4600 50  0001 C CNN
	1    3200 4600
	0    1    1    0   
$EndComp
$Comp
L LED:WS2812B LED2
U 1 1 6651A007
P 4500 4600
F 0 "LED2" H 4844 4646 50  0000 L CNN
F 1 "WS2812B" H 4844 4555 50  0000 L CNN
F 2 "LED_SMD:LED_WS2812B_PLCC4_5.0x5.0mm_P3.2mm" H 4550 4300 50  0001 L TNN
F 3 "~" H 4600 4225 50  0001 L TNN
	1    4500 4600
	1    0    0    -1  
$EndComp
$Comp
L Device:C C1
U 1 1 6651A005
P 5500 4600
F 0 "C1" H 5615 4646 50  0000 L CNN
F 1 "100nF" H 5615 4555 50  0000 L CNN
F 2 "Capacitor_SMD:C_0805_2012Metric" H 5538 4450 50  0001 C CNN
F 3 "~" H 5500 4600 50  0001 C CNN
	1    5500 4600
	1    0    0    -1  
$EndComp
$Comp
L power:GND #PWR03
U 1 1 6651A009
P 4300 2400
F 0 "#PWR03" H 4300 2150 50  0001 C CNN
F 1 "GND" H 4305 2227 50  0000 C CNN
F 2 "" H 4300 2400 50  0001 C CNN
F 3 "" H 4300 2400 50  0001 C CNN
	1    4300 2400
	1    0    0    -1  
$EndComp
$Comp
L power:GND #PWR04
U 1 1 6651A00A
P 5600 1900
F 0 "#PWR04" H 5600 1650 50  0001 C CNN
F 1 "GND" H 5605 1727 50  0000 C CNN
F 2 "" H 5600 1900 50  0001 C CNN
F 3 "" H 5600 1900 50  0001 C CNN
	1    5600 1900
	1    0    0    -1  
$EndComp
$Comp
L power:GND #PWR05
U 1 1 6651A00B
P 2200 4100
F 0 "#PWR05" H 2200 3850 50  0001 C CNN
F 1 "GND" H 2205 3927 50  0000 C CNN
F 2 "" H 2200 4100 50  0001 C CNN
F 3 "" H 2200 4100 50  0001 C CNN
	1    2200 4100
	1    0    0    -1  
$EndComp
$Comp
L power:GND #PWR06
U 1 1 6651A00C
P 4500 5100
F 0 "#PWR06" H 4500 4850 50  0001 C CNN
F 1 "GND" H 4505 4927 50  0000 C CNN
F 2 "" H 4500 5100 50  0001 C CNN
F 3 "" H 4500 5100 50  0001 C CNN
	1    4500 5100
	1    0    0    -1  
$EndComp
$Comp
L power:+3.3V #PWR07
U 1 1 6651A00D
P 4500 4200
F 0 "#PWR07" H 4500 4050 50  0001 C CNN
F 1 "+3.3V" H 4515 4373 50  0000 C CNN
F 2 "" H 4500 4200 50  0001 C CNN
F 3 "" H 4500 4200 50  0001 C CNN
	1    4500 4200
	1    0    0    -1  
$EndComp
$Comp
L power:GND #PWR08
U 1 1 6651A00E
P 5500 4900
F 0 "#PWR08" H 5500 4650 50  0001 C CNN
F 1 "GND" H 5505 4727 50  0000 C CNN
F 2 "" H 5500 4900 50  0001 C CNN
F 3 "" H 5500 4900 50  0001 C CNN
	1    5500 4900
	1    0    0    -1  
$EndComp
$Comp
L power:+3.3V #PWR09
U 1 1 6651A00F
P 5500 4300
F 0 "#PWR09" H 5500 4150 50  0001 C CNN
F 1 "+3.3V" H 5515 4473 50  0000 C CNN
F 2 "" H 5500 4300 50  0001 C CNN
F 3 "" H 5500 4300 50  0001 C CNN
	1    5500 4300
	1    0    0    -1  
$EndComp
```

- [ ] **Step 2: Verify the file is valid**

Run: `grep -c '\$Comp' hardware/gate-controller.sch && grep -c '\$EndComp' hardware/gate-controller.sch`

Expected: Both counts should be 18 (2 original connectors + 2 original power + 8 new components + 6 new power = 18).

- [ ] **Step 3: Commit**

```bash
git add hardware/gate-controller.sch
git commit -m "Add gate controller circuit components to schematic"
```

---

### Task 2: Add .gitignore for KiCad files

**Files:**
- Create: `hardware/.gitignore`

KiCad generates many temporary/backup files. These should not be committed.

- [ ] **Step 1: Create the .gitignore**

Write `hardware/.gitignore`:

```
# KiCad backup and temp files
*.bak
*.bck
*-backups/
*.kicad_pcb-bak
*.sch-bak
*~
\#*
_autosave-*
*.tmp
fp-info-cache
*.dsn
*.ses
*.kicad_prl

# KiCad 8 auto-generated
*.kicad_dru

# Gerber outputs (regenerate from source)
gerbers/
```

- [ ] **Step 2: Commit**

```bash
git add hardware/.gitignore
git commit -m "Add .gitignore for KiCad temp files"
```

---

### Task 3: Wire schematic in KiCad (MANUAL — requires KiCad GUI)

**Files:**
- Modify: `hardware/gate-controller.sch` (via KiCad GUI)

This task must be done interactively in KiCad. An agent cannot perform these steps.

- [ ] **Step 1: Open the project in KiCad 8**

Open `hardware/gate-controller.pro` in KiCad 8. It will prompt to auto-convert from KiCad 5 format — accept. This creates `.kicad_sch`, `.kicad_pro`, and `.kicad_pcb` files in KiCad 8 format.

- [ ] **Step 2: Verify component placement**

Open the schematic editor. You should see:
- **Right side:** Feather pin headers (J1, J2) with labeled pins — this is from the template
- **Left side (boxed area):** All new components (R1, Q1, J3, R2, LED1, R3, LED2, C1) with power symbols

If any components overlap or are hard to read, drag them to better positions. The exact positions don't matter as long as the wiring is clear.

- [ ] **Step 3: Wire the transistor switch subcircuit**

Draw wires for this circuit:

```
A0 --+-- R1 (1k) -- Q1 base
     |                Q1 collector -- J3 pin 1
     |                Q1 emitter -- GND
     |                J3 pin 2 -- GND
     +-- (branches to LED subcircuit, step 4)
```

Specific connections:
1. Place a net label `A0` on a wire stub attached to R1 pin 1 (left end of horizontal R1)
2. Draw a wire from R1 pin 2 (right end) to Q1 base (left pin)
3. Draw a wire from Q1 collector (top pin) to J3 pin 1 (top pin of screw terminal)
4. Connect Q1 emitter (bottom pin) to the GND symbol below it
5. Connect J3 pin 2 (bottom pin of screw terminal) to its GND symbol

- [ ] **Step 4: Wire the gate LED subcircuit**

```
A0 -- R2 (330) -- LED1 anode
                   LED1 cathode -- GND
```

Connections:
1. Place a net label `A0` on a wire stub attached to R2 pin 1 (top of vertical R2)
2. Draw a wire from R2 pin 2 (bottom) to LED1 anode (top pin)
3. Connect LED1 cathode (bottom pin) to the GND symbol below it

- [ ] **Step 5: Wire the NeoPixel subcircuit**

```
A1 -- R3 (330) -- WS2812B DIN
                   WS2812B VDD -- +3.3V
                   WS2812B VSS -- GND
                   WS2812B DOUT -- (no connect)
```

Connections:
1. Place a net label `A1` on a wire stub attached to R3 pin 1 (left end of horizontal R3)
2. Draw a wire from R3 pin 2 (right end) to WS2812B DIN pin
3. Connect WS2812B VDD to the +3.3V symbol above it
4. Connect WS2812B VSS to the GND symbol below it
5. Place a "No Connect" flag (X) on WS2812B DOUT pin

- [ ] **Step 6: Wire the bypass capacitor**

```
C1 pin 1 -- +3.3V
C1 pin 2 -- GND
```

1. Connect C1 pin 1 (top) to its +3.3V symbol
2. Connect C1 pin 2 (bottom) to its GND symbol

- [ ] **Step 7: Run ERC (Electrical Rules Check)**

In KiCad's schematic editor: **Inspect → Electrical Rules Checker → Run ERC**

Expected: 0 errors. Warnings about unconnected Feather pins (A2–A5, SCK, MOSI, etc.) are OK — those are unused. Add "No Connect" flags to unused pins to silence warnings if desired.

If ERC shows errors for missing connections, fix the wiring. Common issues:
- Wire doesn't quite touch a pin — extend it to snap to the pin endpoint
- Missing power flag — add a `PWR_FLAG` symbol to the GND or +3.3V net

- [ ] **Step 8: Save and commit**

```bash
git add hardware/
git commit -m "Wire gate controller schematic and pass ERC"
```

---

### Task 4: PCB layout — import, place, route (MANUAL — requires KiCad GUI)

**Files:**
- Modify: `hardware/gate-controller.kicad_pcb` (via KiCad GUI)

- [ ] **Step 1: Update PCB from schematic**

In KiCad's PCB editor: **Tools → Update PCB from Schematic**

This imports all new components as footprints. They'll appear as a cluster near the board — you need to place them.

- [ ] **Step 2: Place components on the PCB**

The board is 50.8 x 22.86mm. Headers run along the top and bottom edges. Available space is the interior rectangle between the pin rows, roughly 40mm x 12mm.

Placement guidelines (coordinates in mm from the board's top-left corner at 25.4, 25.4):

| Component | Suggested position | Notes |
|---|---|---|
| J3 (screw terminal) | Right edge, between mounting holes | Place at board edge for easy wire access. The 5.08mm terminal is ~10mm wide. |
| Q1 (TO-92) | Near J3, slightly left | Keep collector trace to J3 short |
| R1 (0805) | Between pin header (A0 pad) and Q1 | Route A0 → R1 → Q1 base |
| LED1 (0805) | Center of board, visible from top | Hardwired gate indicator |
| R2 (0805) | Between A0 pad and LED1 | |
| LED2 (WS2812B, 5050) | Center of board, near LED1 | RGB status — place for visibility |
| R3 (0805) | Between A1 pad and LED2 | |
| C1 (0805) | Adjacent to LED2 | Bypass cap — keep close to WS2812B |

Key constraints:
- J3 must be at a board edge (right or top) so wires can exit
- Q1 (TO-92) is the largest component at ~5mm wide — ensure it clears mounting holes
- Keep bypass cap C1 within 5mm of WS2812B
- All SMD parts on the top (F.Cu) side

- [ ] **Step 3: Route traces**

Trace widths:
- Signal traces (A0→R1, A1→R3, R1→Q1 base, etc.): **0.25mm** (default)
- Power traces (3.3V to WS2812B, GND): **0.4mm** minimum
- Q1 collector→J3: **0.5mm** (carries the dry-contact current)

Routing order (easiest first):
1. GND connections — consider a small GND copper pour in unused areas
2. +3.3V to WS2812B VDD and C1
3. A0 → R1 → Q1 base
4. Q1 collector → J3 pin 1
5. Q1 emitter → GND, J3 pin 2 → GND
6. A0 → R2 → LED1 → GND
7. A1 → R3 → WS2812B DIN

All traces can be routed on the front copper layer (F.Cu). Use the back layer (B.Cu) only if you need to cross traces.

- [ ] **Step 4: Add silkscreen labels**

Add text labels on F.SilkS:
- "GATE" near J3
- "+" and "-" near J3 pins (or "GATE" and "GND")
- "LED" near LED1
- Board name: "Gate Controller Wing v1.0"

- [ ] **Step 5: Run DRC (Design Rules Check)**

**Inspect → Design Rules Checker → Run DRC**

Expected: 0 errors, 0 unconnected nets. Fix any violations (usually clearance issues — move components apart slightly).

- [ ] **Step 6: Save and commit**

```bash
git add hardware/
git commit -m "Place and route gate controller PCB"
```

---

### Task 5: Update README and final commit

**Files:**
- Modify: `README`

- [ ] **Step 1: Update README with hardware section**

Replace the contents of the `README` file with:

```
# Gate Controller

Alexa-enabled driveway gate controller with custom FeatherWing PCB.

## Software

Python server running on a Raspberry Pi (or Feather with WiFi) that controls
the gate via GPIO. Supports Alexa voice commands and HTTP API.

### API

- `POST /hold` — hold gate open (body: seconds, default 1)
- `POST /hold/cancel` — release gate
- `GET /hold` — check if gate is held

### Running

```bash
docker build -t gate_controller .
docker run -p 80:80 --privileged gate_controller
```

## Hardware

FeatherWing PCB in `hardware/` — designed in KiCad.

### Circuit

- **NPN switch**: GPIO A0 → 1kΩ → 2N3904 base; collector/emitter across
  LiftMaster dry-contact input via screw terminal
- **Gate LED**: Green 0805 LED on A0 — lights when gate is held open
- **NeoPixel**: WS2812B on A1 — firmware-controlled RGB status
- **Bypass cap**: 100nF across WS2812B power rails

### BOM

| Ref | Part | Value | Package |
|-----|---|---|---|
| Q1 | 2N3904 | NPN | TO-92 |
| R1 | Resistor | 1kΩ | 0805 |
| R2 | Resistor | 330Ω | 0805 |
| R3 | Resistor | 330Ω | 0805 |
| C1 | Capacitor | 100nF | 0805 |
| LED1 | LED | Green | 0805 |
| LED2 | WS2812B | RGB | 5050 |
| J3 | Screw terminal | 2-pos | 5.08mm |

### Fabrication

Generate Gerber files from KiCad: File → Fabrication Outputs → Gerbers.
Upload to JLCPCB, OSH Park, or PCBWay.
```

- [ ] **Step 2: Rename README to README.md**

```bash
cd ~/depot/github.com/nstielau/gate_controller
git mv README README.md
```

- [ ] **Step 3: Commit and push**

```bash
git add README.md
git commit -m "Update README with hardware docs and BOM"
git push
```

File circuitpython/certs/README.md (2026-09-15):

# Firebase TLS trust roots

`google-roots.pem` contains the public GTS Root R1, R2, R3 and R4 certificates,
downloaded on 2026-09-14 from Google's HTTPS certificate repository:

- https://pki.goog/repo/certs/gtsr1.pem
- https://pki.goog/repo/certs/gtsr2.pem
- https://pki.goog/repo/certs/gtsr3.pem
- https://pki.goog/repo/certs/gtsr4.pem

The OTA HTTP client explicitly loads these roots and verifies the Firebase
hostname. The tested CircuitPython 10.3.0 built-in certificate bundle failed
Firebase validation; explicitly loading these roots succeeded. These are public
certificates, not credentials. Deploy and update them through USB, independently
of application releases. Never replace them with a server's short-lived leaf
certificate or disable TLS verification to work around a trust failure.

The separate MQTT CA is supplied from the ignored repository-root
`emqxsl-ca.crt`; it is not part of this public bundle.

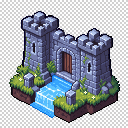
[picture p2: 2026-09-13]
web/drawbridge-loader-background.png

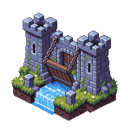
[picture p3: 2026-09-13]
web/drawbridge-castle-128.png

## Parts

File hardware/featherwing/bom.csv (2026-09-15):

Reference | Value | Description | Tolerance | Manufacturer | Manufacturer Part Number | Footprint | Quantity | Populate
J1 | Feather 16 | Feather-compatible 1x16 male header, 2.54 mm, 3/6 mm pins |  | XKB | X6511WV-16H-C30D60 | Drawbridge:FeatherHeader16 | 1 | Yes
J2 | Feather 12 | Feather-compatible 1x12 male header, 2.54 mm, 3/6 mm pins |  | XKB | X6511WV-12H-C30D60 | Drawbridge:FeatherHeader12 | 1 | Yes
R1 | 1k | 1 kOhm 5% axial resistor, 0.25 W | 5% | Yageo | CFR-25JB-52-1K | Resistor_THT:R_Axial_DIN0207_L6.3mm_D2.5mm_P7.62mm_Horizontal | 1 | Yes
R2 | 100k | 100 kOhm 5% axial resistor, 0.5 W | 5% | Yageo | MFR50SJT-52-100K | Resistor_THT:R_Axial_DIN0207_L6.3mm_D2.5mm_P7.62mm_Horizontal | 1 | Yes
Q1 | 2N3904 | NPN transistor, TO-92, EBC |  | onsemi | 2N3904BU | Package_TO_SOT_THT:TO-92_Inline | 1 | Yes
J3 | OUT / GND | 2-position screw terminal, 2.54 mm, side wire entry |  | Phoenix Contact | 1725656 | Drawbridge:ExitTerminal | 1 | Yes
R3 | 1k | 1 kOhm 5% axial resistor, 0.25 W | 5% | Yageo | CFR-25JB-52-1K | Resistor_THT:R_Axial_DIN0207_L6.3mm_D2.5mm_P7.62mm_Horizontal | 1 | Yes
D1 | WIFI | 3 mm cool-white LED, THT |  | Everlight | 204-15UTC/S400-X9 | LED_THT:LED_D3.0mm | 1 | Yes
R4 | 1k | 1 kOhm 5% axial resistor, 0.25 W | 5% | Yageo | CFR-25JB-52-1K | Resistor_THT:R_Axial_DIN0207_L6.3mm_D2.5mm_P7.62mm_Horizontal | 1 | Yes
D2 | MQTT | 3 mm blue LED, THT |  | Everlight | 204-10SUBC/S400-A4 | LED_THT:LED_D3.0mm | 1 | Yes
R5 | 1k | 1 kOhm 5% axial resistor, 0.25 W | 5% | Yageo | CFR-25JB-52-1K | Resistor_THT:R_Axial_DIN0207_L6.3mm_D2.5mm_P7.62mm_Horizontal | 1 | Yes
D3 | HOLD | 3 mm green LED, THT |  | Everlight | 204-10SUGD/S400-A5 | LED_THT:LED_D3.0mm | 1 | Yes

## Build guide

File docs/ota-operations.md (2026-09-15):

# OTA and administrator operations

The implementation is opt-in and currently targets the XIAO ESP32S3 with
CircuitPython 10, board ID `seeed_xiao_esp32_s3_sense` (the installed
Sense firmware build). Its D0/D1/D2/D9/D10 assignments match the documented XIAO
header pins. Initial installation and rollback have passed physical bench
checks; recovery and power-loss qualification is still in progress. Do not
enable a field controller until the checklist below passes. The FeatherWing
PCB's portable headers do not imply that these XIAO firmware pins work on a Feather.

Device `b3640c` is enrolled and opted in (`OTA_ENABLED = 1`). It installed and
confirmed release 1.0.0 over TLS as sequence 2. Deliberate syntax-error,
startup-exception and watchdog-lockup candidates rolled back to that confirmed
copy. Approved release 1.0.0 is now assigned as sequence 6, above the fault-test
sequences. See [the bench validation record](ota-bench-validation.md) for
observed results, local evidence and outstanding checks. GPIO logs establish
software writes, not electrical output or gate position.

The bench probe found three bootstrap issues that host tests missed: CircuitPython
does not support bytearray slice deletion, and its built-in certificate bundle
failed Firebase verification, and CircuitPython 10.1+ returns the OTA enable
setting as a string. Use the corrected USB deployment, including
`certs/google-roots.pem`; the source archive at the initial firmware-v1.0.0 tag
predates these fixes. The release's application file itself is unchanged.

## Administrators

Open the profile dropdown and choose **Administration**. This item appears
only after the server confirms the signed-in Google account is an admin.
Administrators can add/remove administrators and assign/pause firmware updates
for enrolled devices. They do not automatically gain gate-control access;
existing gate UID allowlists and all command checks remain in place.

Add an administrator by their Google email before or after their first login.
Role records are keyed by the SHA-256 of a normalized, verified Google email;
case differences are ignored, but aliases/dots are not rewritten. Every request
still requires verified Google sign-in and App Check. Role checks occur again
inside each write transaction, so revoking a role invalidates subsequent writes.
The owner `nick.stielau@gmail.com` cannot be removed in the UI.

One-time owner initialization, using Nick's project IAM credentials:

```sh
make admin-seed
```

`admins/` stores assignments and `adminAudit/` stores mutations. Normal browser
Firestore access remains denied. Admin actions use request IDs, freshness
checks, and transactional deduplication; retrying the same request cannot
increment a deployment twice. Use Refresh after an uncertain response.

## Firmware boundaries

- `boot.py` chooses USB/device filesystem ownership. USB-managed.
- `code.py` owns provisioning, NVM, Wi-Fi/MQTT, physical output leases, loader,
  watchdog, and update scheduling. USB-managed.
- `lib/gate_ota.py` owns two application slots and checksummed journals.
  `lib/gate_http.py` is a bounded HTTPS client. Both are USB-managed.
- Root `drawbridge.py` is the USB-installed recovery application. It contains
  command policy and the independent indicator timers.
- `certs/google-roots.pem` contains Google's public GTS roots for Firebase TLS,
  loaded explicitly with hostname verification. It is USB-managed; certificate
  sources and update guidance are in `circuitpython/certs/README.md`.
- `/ota/app0.py` and `/ota/app1.py` are OTA slots. Only one verified candidate
  is selected at a time. OTA never overwrites the root recovery copy.
- `/ota/state0.json` and `/ota/state1.json` alternate checksummed generations.
  A torn new journal leaves the earlier complete record available.

The API boundary is a development convention, not a sandbox. Trusted Python
can import other modules. TLS-authenticated Firebase selects the SHA-256 of
trusted release code. Signed manifests and independent signing-key protection
are not implemented.

D10 is initialized LOW before the temporary D0/D1/D2 diagnostic. Bootstrap
validates hold durations and owns the monotonic deadline. OTA starts only while
idle; each download chunk services MQTT/outputs and aborts when a hold arrives.
DNS/TLS/socket calls can still block briefly, as with existing MQTT connection
attempts. Timers are software serviced, not hard real-time electrical limits.

## Initial enrollment and physical recovery

Prepare a disconnected bench board first. Current installation requires one
USB deployment, because old firmware has no updater.

```sh
make setup
make test
make deploy
make ota-bucket-setup
make ota-enroll DEVICE_ID=b3640c
make ota-provision DEVICE_ID=b3640c
```

Use the board's actual lowercase chip suffix from its boot log. Enrollment
creates a random per-device credential in ignored `artifacts/ota/<id>.env`
with owner-only file permissions. Only its SHA-256 goes to Firestore. The
provisioner writes it to USB-readable `settings.toml`. It also writes
`OTA_DEVICE_ID`; runtime refuses network updates if this does not match the chip.
Enrollment and provisioning leave OTA disabled. Re-enrollment refuses to
silently replace an existing credential or local enrollment file.

After completing the bench checks, explicitly opt in:

```sh
make ota-provision DEVICE_ID=b3640c OTA_ARGS=--enable
```

Then hard-reset or power-cycle the board: changing `boot.py` or filesystem
ownership requires a full boot. With `OTA_ENABLED = 1`, `boot.py` samples D9
(GPIO8 on this XIAO only) using its internal pull-up. **Hold D9 to GND during
reset to enter USB-writable maintenance mode.** D9 must otherwise remain unused.
Normal field mode gives CircuitPython write ownership of CIRCUITPY; do not
bypass concurrent-write protection. Maintenance mode disables OTA even if the
setting is enabled. To disable OTA persistently, set `OTA_ENABLED = 0` via USB
and hard-reset. An unsupported board remains in USB mode.
Missing saved Wi-Fi/MQTT configuration runs the recovery application and portal
without starting an OTA trial or watchdog.

When repairing an OTA-installed application by USB, enter maintenance mode,
run `make deploy`, and remove the two `/ota/state*.json` records before returning
to field mode. This selects the new root recovery file; otherwise a confirmed
OTA slot remains selected. Keep a copy of journals/logs before repair.
To revoke a lost OTA credential, delete `otaCredentialHash` from that device
using project IAM and pause its target. Rotate the device and the ignored local
credential deliberately; it is independent of its MQTT identity.

## Base and application versions

Normal OTA development edits only `circuitpython/drawbridge.py`. The USB-managed
base is `boot.py`, `code.py`, libraries and public certificates. The pre-commit
guard rejects staged base changes unless they include an increased
`BASE_VERSION` in `lib/gate_base.py` and a change note in
`docs/base-firmware/<version>.md`. It checks the index, so an unstaged bump does
not approve a staged edit. It also catches removed/renamed files and MPY changes.
This is an accident-prevention guard, not a security boundary against an actor
who can change hooks; do not bypass it with SKIP or --no-verify.

The device reports two independent versions: `version` is the selected app,
`base_version` is the installed USB bundle. MQTT also preserves the `bootstrap`
alias. Administration shows, for example, “App 1.0.9 · Base 1.0.1”. These are
separate release histories, not numbers to subtract. The timestamp still means
last report, not current reachability. Older reports show “Base not reported”.
The CircuitPython interpreter and app compatibility API are separate again.

Future GitHub releases bundle `base-firmware.zip` and `base-manifest.json`
alongside the single-file OTA app and its manifest. The base manifest records
its semantic version, full release commit and file hashes. Its aggregate hash
excludes the bundled root recovery app, whose hash is recorded separately.
Two app releases may therefore carry the same base version/digest. The ZIP is
for deliberate USB maintenance and excludes device settings, credentials and
the CircuitPython interpreter. Firebase continues to mirror only drawbridge.py.
The existing 1.0.0/1.0.1 releases are unchanged.

Base 1.0.1 adds reporting and incorporates the previously tested USB fixes.
It has not been installed on the board yet. Install through the existing D9
maintenance workflow and run hardware verification before claiming the new base
is in use. An OTA-only upgrade cannot add reporting to an older bootstrap.

## Releasing and selecting firmware

Release assets come from a clean, tagged Git commit. Update `APP_VERSION` in
`circuitpython/drawbridge.py`, run tests, commit, and push a matching tag such as
`firmware-v1.0.1` before publishing. No tool automatically commits or pushes code.

```sh
make firmware-build VERSION=1.0.1
make firmware-release VERSION=1.0.1
make firmware-import VERSION=1.0.1
```

Build runs offline tests and checks that the application's version/API matches
the tag at HEAD. Publish creates a GitHub Release containing `drawbridge.py`,
`manifest.json`, `base-firmware.zip`, and `base-manifest.json`. Import verifies the published tag, source commit, bytes, size,
and SHA-256, then mirrors the file to a create-only object in the private
`drawbridge-45487-firmware` bucket. It creates an approved, immutable manifest in
`firmwareReleases/<version>`. Only local IAM tooling can import releases; the
browser cannot upload code or choose arbitrary URLs.

`make ota-bucket-setup` creates the private bucket in `us-east1` and grants the
runtime service account bucket-scoped Object Viewer. Device downloads pass
through the authenticated Firebase `firmwareDevice` HTTP function; devices do
not receive Storage credentials or signed URLs. The endpoint is
`https://drawbridge-45487.firebaseapp.com/device-api/v1/`. Requests use
`X-Device-ID` and a bearer token, with no redirects allowed. Endpoint response
bodies, credentials, and firmware API responses are never service-worker cached.

In Administration, select an imported release for an enrolled, enabled device
and choose **Assign release**. Every assignment gets a newer deployment
sequence, including assigning an older app version as a deliberate rollback.
**Pause updates** stops future checks from receiving a target; it does not
interrupt a download already admitted by the server or undo installed firmware.
Assigning firmware never sends an MQTT hold or changes device access.

Checks start 60–315 seconds after startup, then every six hours plus jitter.
Failed checks back off from one minute to 24 hours. Active holds defer checks.
The client bounds manifests to 4 KiB, artifacts to 64 KiB, socket waits to five
seconds, and each HTTP transfer to 45 seconds plus bounded DNS/TLS setup.
It supports fragmented Content-Length and chunked responses and rejects
compression, redirects, malformed framing, incompatible boards/APIs, short
reads, and digest mismatches.

A candidate is journaled before reload. It must import with matching version
and API, run its loop, and maintain a subscribed MQTT connection for 60 seconds
before confirmation. Failure to become healthy within five minutes rolls back.
A subsequent boot that finds an already-started, unconfirmed trial also rolls
back. A 60-second watchdog in OTA field mode catches loop lockups; it is fed by
the main loop and download servicing, not by a background task. Ordinary network
errors do not explicitly hard-reset the board. Hardware watchdog resets and
filesystem persistence across actual power loss still need bench validation.

The last confirmed slot is retained during the next download. If that slot
fails validation, bootstrap falls back to the USB recovery file. A runtime
exception in an OTA-selected app drives outputs LOW and selects recovery. Filesystem
corruption affecting both journals or the root files still requires USB repair.
No application-level scheme can promise recovery from all FAT/media failures.

Administration displays the last device-reported version/state and timestamp,
separately from the assigned target. Reporting is periodic and best effort;
it does not confirm gate position. MQTT `device_status.firmware` and `GATE_LOG`
also expose the app version and update state without secrets.

## Verification before first field rollout

Automated checks:

```sh
make test
make web-test
make precommit
make test-hardware  # requires a provisioned USB board; observes only
```

Host tests cover candidate verification, two-slot selection, checksummed journal
recovery, trial rollback, transfer failures, size/space limits, replay rejection,
lease separation, and HTTP framing. Firestore emulator tests cover admin grants,
revocation, deduplication, owner protection, device enrollment/target guards,
token scope/revocation, throttling, and deny-all rules. Mobile Chromium/WebKit
exercise admin visibility, role changes, targeting, offline controls, and signout.

On a disconnected bench controller, verify all of these before targeting the
installed gate:

1. Normal USB deploy and unchanged Wi-Fi/MQTT/LED behavior.
2. D9 maintenance recovery after enabling OTA, including after a bad candidate.
3. A real TLS download, app version report, trial confirmation, and later update.
4. Hold deferral and download abort when an explicit short hold arrives.
5. Syntax error, startup exception, loop lockup, and no-MQTT trial rollback.
6. Power removal during slot write and each journal transition; inspect the
   selected bytes and actual D10 state on restart.
7. Full storage, damaged journal/slot, disabled token/device, and paused target.
8. Reassignment to the previous app under a newer deployment sequence.

Use a short explicit bench hold and optical/electrical checks in addition to
logs. Do not treat host filesystem fault simulation as physical flash testing.
After bench validation, target one canary device and observe it for a week
before expanding. Channel-wide promotion and signed manifests remain future
work; this implementation provides explicit per-device assignments.

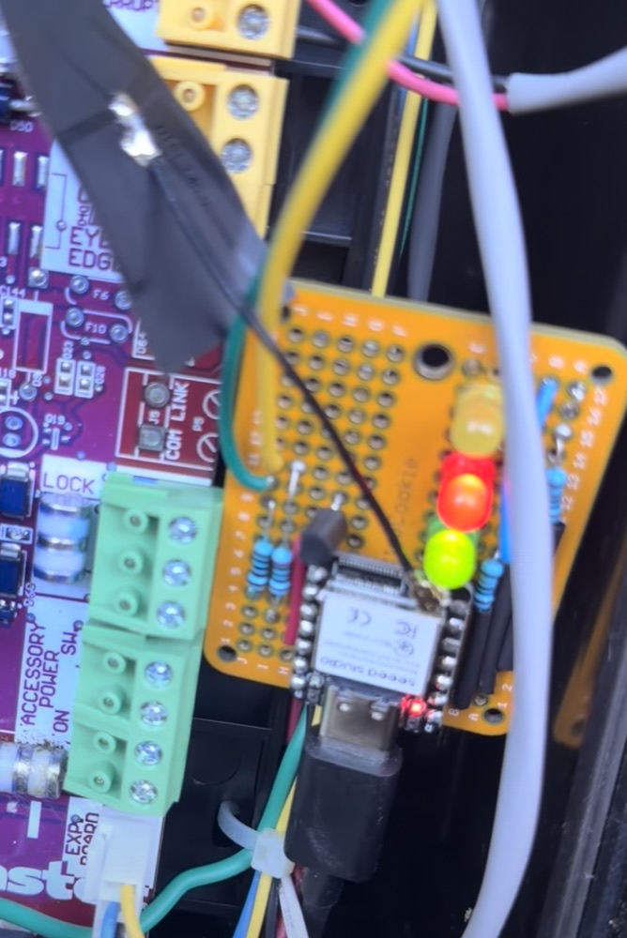
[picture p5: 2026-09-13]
docs/wiring-installed.jpg

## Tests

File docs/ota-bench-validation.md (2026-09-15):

# OTA bench validation — 2026-09-14

Board `b3640c`, XIAO ESP32S3 Sense firmware, CircuitPython 10.3.0. The owner
confirmed that the gate output wires were disconnected. Tests below measure
software GPIO state, not gate motion or electrical output.

## Observed on the board

| Check | Result | Local evidence under `artifacts/ota-bench/` |
| --- | --- | --- |
| SHA-256 and fragmented HTTP parsing | Passed after parser fix | `probe-output.log` |
| Authenticated Firebase download | All 2,932 bytes match release 1.0.0 SHA-256 | `probe-output.log` |
| Timed MQTT hold | D10 HIGH for about 3 seconds, then LOW; D2 samples 125–157 ms | `indicators.log` |
| Connectivity and indicators | 70 seconds, eight heartbeats, four D2 samples | `indicators-summary.log` |
| Normal OTA boot | `GATE_BOOT mode=ota`; macOS mounts CIRCUITPY read-only | `boot_out.txt` on board |
| First OTA install | Sequence 2 staged, booted as trial, reconnected MQTT, confirmed after 60 seconds | `first-update.log` |
| Invalid Python candidate | Locally staged sequence 3 rolled back to confirmed sequence 2 | `syntax-fault.log` |
| Startup exception | Locally staged sequence 4 rolled back to confirmed sequence 2 | `startup-fault.log` |
| Loop lockup | Locally staged sequence 5 triggered the hardware watchdog; board rebooted and recovered sequence 2 | `watchdog-fault.log`, `watchdog-reset.log` |
| Hold deferral | D10 HIGH for 120.004 s; update staged 3.306 s after release, never during hold | `hold-deferral.json`, `update.log` |
| Update after failures | Sequence 6 installed in the other slot and confirmed after its MQTT health trial | `update.log`, `update-summary.log` |

The fault candidates were injected locally through USB REPL into the inactive
slot. They were not published to GitHub or approved in Firebase. The previous
confirmed application survived each test. Firebase has subsequently been
assigned approved release 1.0.0 as sequence 6, above the consumed fault-test
sequences. This second installation is confirmed and the board's MQTT status
reports version 1.0.0, state current, with no active hold.

## Fixes required by the physical tests

- Replace bytearray slice deletion with slicing; CircuitPython rejects item
  deletion. Host regression tests now model that restriction.
- Load Google's public GTS root certificates explicitly for Firebase HTTPS.
  The built-in bundle failed validation. Certificate and hostname verification
  remain enabled; `certs/README.md` records the certificate sources.
- Accept the string `"1"` in `boot.py`: CircuitPython 10.1+ returns strings from
  `os.getenv`, even for TOML integers. Tests cover both older integer and newer
  string representations, with D9 HIGH and LOW.

These are USB bootstrap fixes. The immutable GitHub application asset remains
unchanged. Use the corrected repository bootstrap, not the bootstrap files in
the original firmware-v1.0.0 source archive. The offline suite has 55 passing
tests, and secret/lint hooks passed.

## Still outstanding

- Repeat D9 recovery with the corrected boot setting check. The initial test
  was inconclusive because the setting bug kept every boot in USB mode.
- Confirm the Firebase device version report.
- Remove power during slot writes and journal transitions; a watchdog reset
  is not a power-loss test.
- Real no-MQTT trial timeout, full storage, damaged files, token revocation,
  paused target, and a hold arriving during download. Host tests cover several
  of these paths but do not establish physical flash/power-loss behavior.

Do not describe this as completed field qualification. Keep the controller
disconnected while conducting the remaining fault and recovery tests.

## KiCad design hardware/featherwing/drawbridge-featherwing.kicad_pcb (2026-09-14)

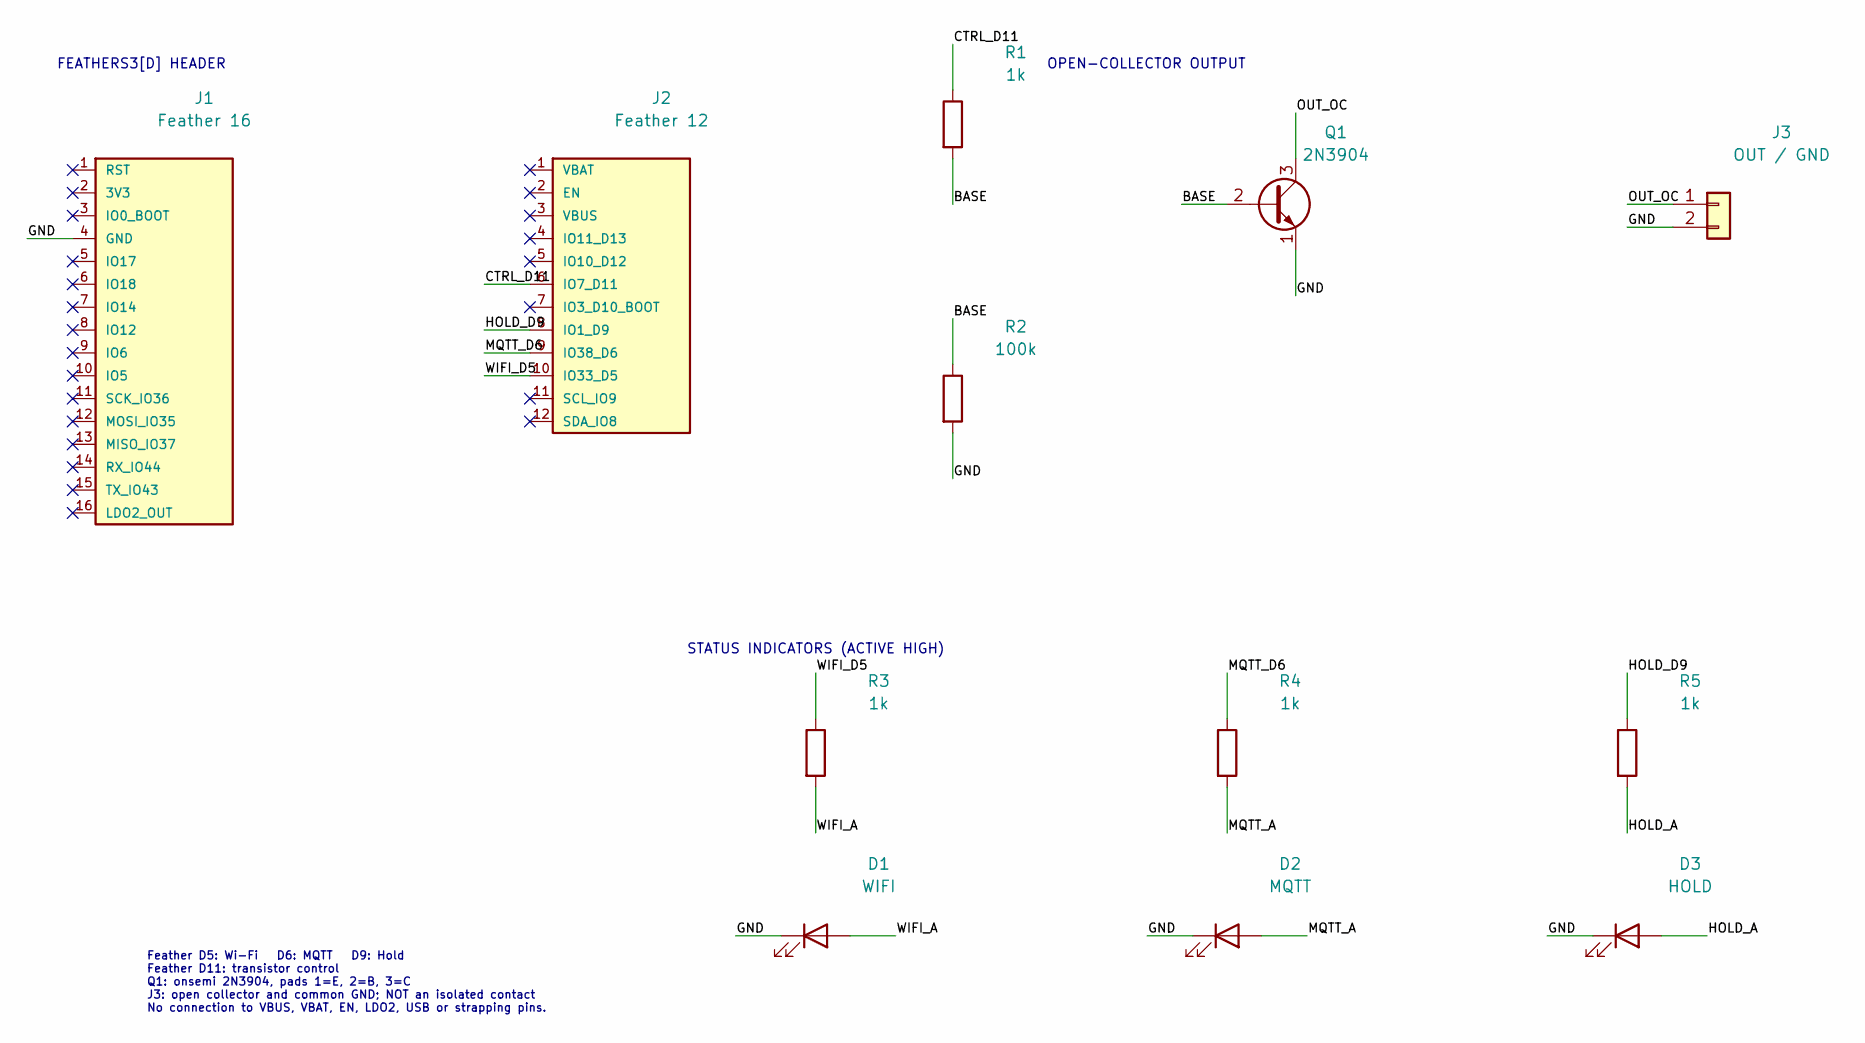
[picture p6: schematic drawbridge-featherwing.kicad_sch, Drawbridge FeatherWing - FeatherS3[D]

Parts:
D1: WIFI; LED_D3.0mm
D2: MQTT; LED_D3.0mm
D3: HOLD; LED_D3.0mm
J1: Feather 16; FeatherHeader16
J2: Feather 12; FeatherHeader12
J3: OUT / GND; ExitTerminal
Q1: 2N3904; TO-92_Inline
R1, R3, R4, R5: 1k; R_Axial_DIN0207_L6.3mm_D2.5mm_P7.62mm_Horizontal
R2: 100k; R_Axial_DIN0207_L6.3mm_D2.5mm_P7.62mm_Horizontal

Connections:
/BASE: Q1.2 (B), R1.2, R2.1
/CTRL_D11: J2.6 (IO7_D11), R1.1
/GND: D1.1 (K), D2.1 (K), D3.1 (K), J1.4 (GND), J3.2, Q1.1 (E), R2.2
/HOLD_A: D3.2 (A), R5.2
/HOLD_D9: J2.8 (IO1_D9), R5.1
/MQTT_A: D2.2 (A), R4.2
/MQTT_D6: J2.9 (IO38_D6), R4.1
/OUT_OC: J3.1, Q1.3 (C)
/WIFI_A: D1.2 (A), R3.2
/WIFI_D5: J2.10 (IO33_D5), R3.1

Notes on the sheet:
FEATHERS3[D] HEADER
OPEN-COLLECTOR OUTPUT
STATUS INDICATORS (ACTIVE HIGH)
Feather D5: Wi-Fi D6: MQTT D9: Hold Feather D11: transistor control Q1: onsemi 2N3904, pads 1=E, 2=B, 3=C J3: open collector and common GND; NOT an isolated contact No connection to VBUS, VBAT, EN, LDO2, USB or strapping pins.

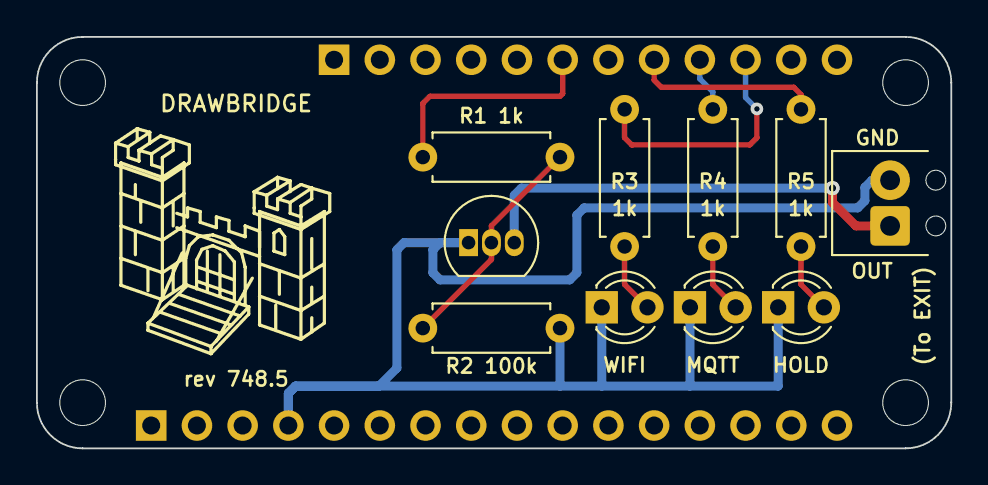
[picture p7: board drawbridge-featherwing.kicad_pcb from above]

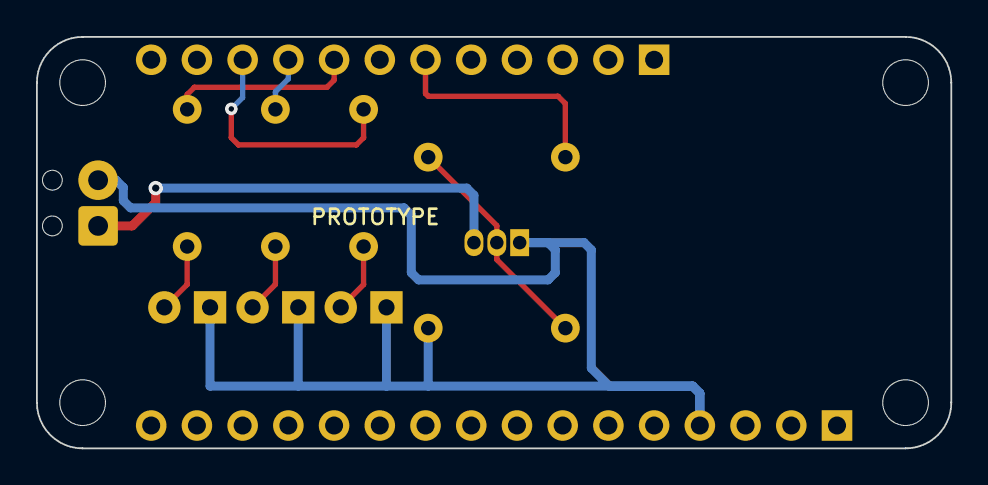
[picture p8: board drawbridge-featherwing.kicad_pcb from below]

Board: 2 copper layers, 50.8 x 22.9 mm, 16 parts (2 on the bottom side), 10 nets.

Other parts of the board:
H1, H2, H3, H4: MountingHole_2.5mm; FeatherMount

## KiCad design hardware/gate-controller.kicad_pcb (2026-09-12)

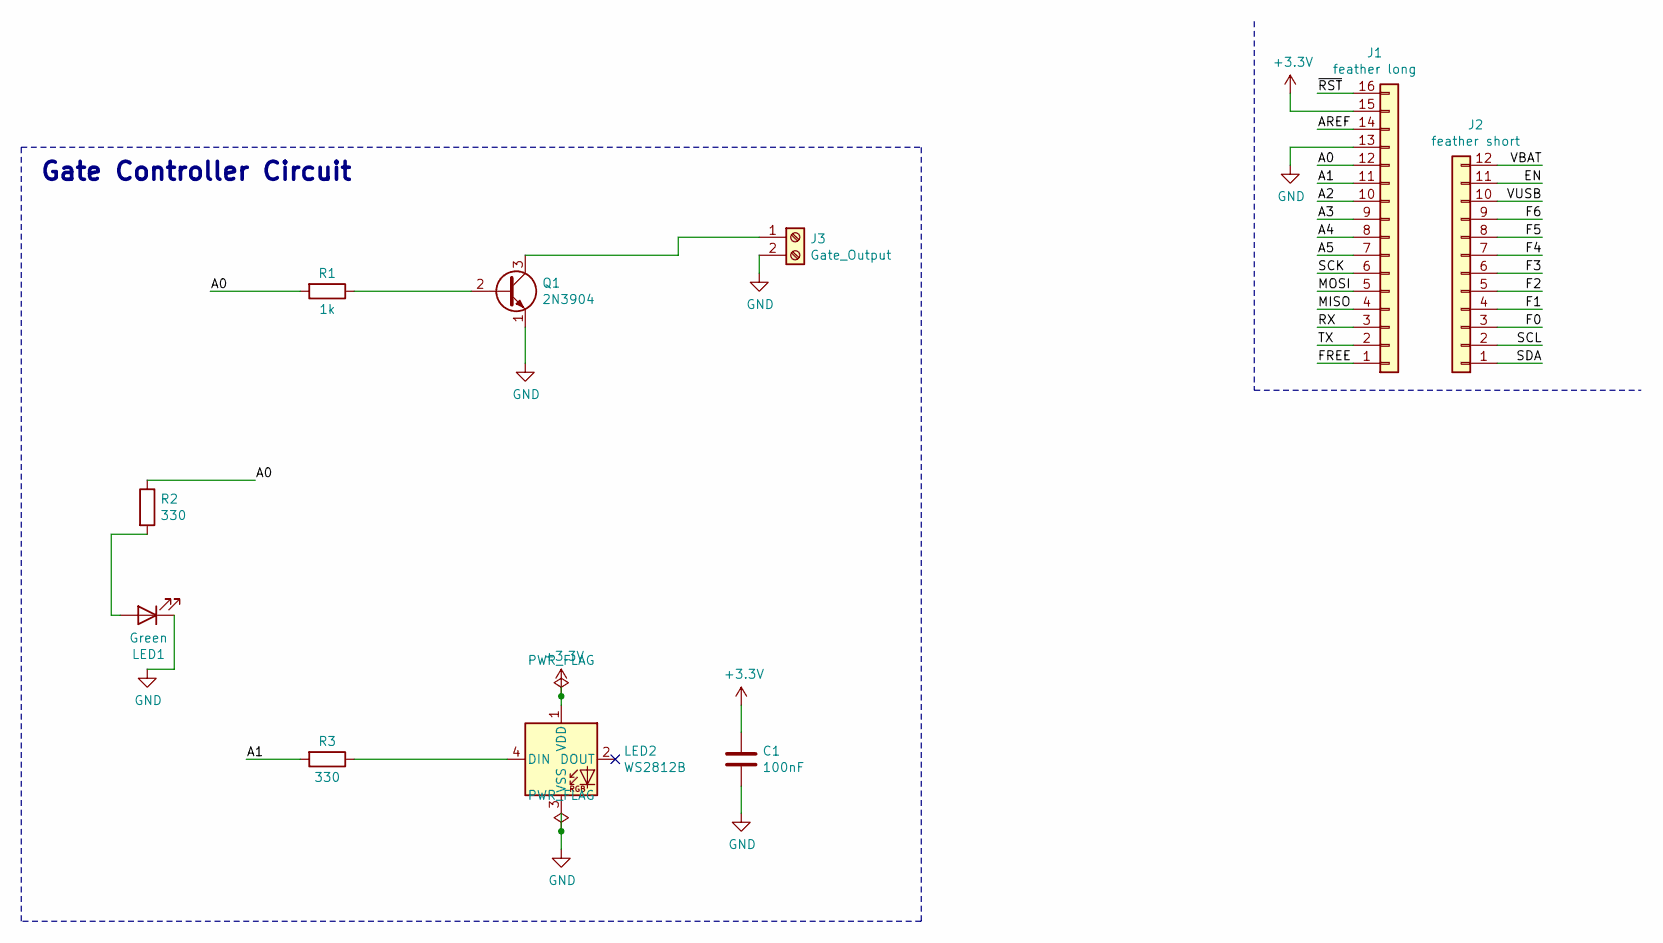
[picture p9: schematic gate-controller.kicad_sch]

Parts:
C1: 100nF; C_0805_2012Metric
J1: feather long; PinHeader_1x16_P2.54mm_Vertical
J2: feather short; PinHeader_1x12_P2.54mm_Vertical
J3: Gate_Output; TerminalBlock_Phoenix_MKDS-1,5-2-5.08_1x02_P5.08mm_Horizont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
LED1: Green; LED_0805_2012Metric
LED2: WS2812B; LED_WS2812B_PLCC4_5.0x5.0mm_P3.2mm
Q1: 2N3904; TO-92_Inline
R1: 1k; R_0805_2012Metric
R2, R3: 330; R_0805_2012Metric

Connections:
+3.3V: C1.1, J1.15, LED2.1 (VDD)
/A0: J1.12, R1.2, R2.1
/A1: J1.11, R3.2
/A2: J1.10
/A3: J1.9
/A4: J1.8
/A5: J1.7
/AREF: J1.14
/EN: J2.11
/F0: J2.3
/F1: J2.4
/F2: J2.5
/F3: J2.6
/F4: J2.7
/F5: J2.8
/F6: J2.9
/FREE: J1.1
/MISO: J1.4
/MOSI: J1.5
/RX: J1.3
/SCK: J1.6
/SCL: J2.2
/SDA: J2.1
/TX: J1.2
/VBAT: J2.12
/VUSB: J2.10
/~RST: J1.16
GND: C1.2, J1.13, J3.2, LED1.1 (K), LED2.3 (VSS), Q1.1 (E)
unnamed: J3.1, Q1.3 (C)
unnamed: LED1.2 (A), R2.2
unnamed: LED2.4 (DIN), R3.1
unnamed: Q1.2 (B), R1.1

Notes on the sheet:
Gate Controller Circuit

Board: 2 copper layers, 10 parts (2 on the bottom side), 8 nets, no tracks yet.

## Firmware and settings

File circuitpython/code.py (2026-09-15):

"""Wi-Fi and MQTT provisioning for the Gate Controller XIAO ESP32-S3.

Join the open Gate-Setup-* access point and open http://192.168.4.1. The
portal stores Wi-Fi and MQTT credentials in microcontroller.nvm, outside the
USB-mounted CIRCUITPY filesystem.
"""

import json
import ipaddress
import microcontroller
import os
import ssl
import time
import wifi

import adafruit_connection_manager
import adafruit_minimqtt.adafruit_minimqtt as MQTT
import board
import digitalio
import supervisor
from gate_mqtt import GateMQTT, NETWORK_SECONDS
from drawbridge import Indicators, create_app, APP_VERSION
from gate_hold import HoldState
from gate_base import BASE_VERSION


CONFIG_SIZE = min(512, len(microcontroller.nvm))
CONFIG_MAGIC = b"GATE3"
OLD_CONFIG_MAGIC = b"GATE1"
OLD_CONFIG_SIZE = 192

MQTT_BROKER = "jd3a6164.ala.us-east-1.emqxsl.com"
MQTT_PORT = 8883
EMQX_CA_FILE = "/certs/emqxsl-ca.crt"
BOOT_ID = "".join("{:02x}".format(value) for value in os.urandom(6))

TRANSISTOR_CONTROL_PIN = board.D10
WIFI_INDICATOR_PIN = board.D0
MQTT_INDICATOR_PIN = board.D1
HOLD_INDICATOR_PIN = board.D2

led = digitalio.DigitalInOut(board.LED)
led.switch_to_output(value=False)  # Onboard LED is active LOW.

gate_output = None
hold_led = None
wifi_led = None
mqtt_led = None
indicators = Indicators(time.monotonic())
hold = HoldState()
hold_samples_left = 4
application = None
ota_store = None
ota_http = None
ota_version = APP_VERSION
ota_selected = None
ota_trial_started = 0
ota_healthy_since = None
ota_next_check = 0
ota_backoff = 60
ota_state = "disabled"
watchdog_timer = None


class Platform:
    def request_hold(self, seconds, command_id, now):
        # Bootstrap validates and owns the physical output deadline independently.
        hold.apply(
            json.dumps(
                {
                    "version": 1,
                    "type": "hold_gate",
                    "duration_seconds": seconds,
                    "command_id": command_id,
                }
            ),
            now,
        )


def initialize_application(allow_ota=True):
    global application, indicators, ota_store, ota_selected, ota_version
    global ota_trial_started, ota_state, watchdog_timer, ota_next_check
    factory = create_app
    if (
        allow_ota
        and os.getenv("OTA_ENABLED") in (1, "1")
        and board.board_id == "seeed_xiao_esp32_s3_sense"
    ):
        import storage

        if not storage.getmount("/").readonly:
            from gate_ota import UpdateStore
            from watchdog import WatchDogMode

            ota_store = UpdateStore()
            path, ota_selected = ota_store.begin_boot()
            watchdog_timer = microcontroller.watchdog
            watchdog_timer.timeout = 60
            watchdog_timer.mode = WatchDogMode.RESET
            if path:
                namespace = {"__name__": "drawbridge_candidate"}
                with open(path) as source:
                    exec(source.read(), namespace)
                if (
                    namespace.get("APP_API_VERSION") != 1
                    or namespace.get("APP_VERSION") != ota_selected["app_version"]
                ):
                    raise ValueError("invalid_app_interface")
                factory = namespace["create_app"]
                ota_version = namespace["APP_VERSION"]
            ota_state = ota_store.state["outcome"]
            ota_trial_started = time.monotonic()
            ota_next_check = ota_trial_started + 60 + int.from_bytes(os.urandom(1), "big")
    application = factory(Platform(), time.monotonic())
    indicators = application.indicators
    log_event(
        "application_ready",
        version=ota_version,
        base_version=BASE_VERSION,
        ota_state=ota_state,
        board_id=str(board.board_id),
    )


def ota_service(runtime, client):
    global ota_http, ota_state, ota_next_check, ota_backoff, ota_healthy_since
    if ota_store is None:
        return
    now = time.monotonic()
    online = client is not None and wifi.radio.connected
    if watchdog_timer:
        watchdog_timer.feed()
    if ota_store.state["trial"]:
        if online:
            if ota_healthy_since is None:
                ota_healthy_since = now
            if now - ota_healthy_since >= 60:
                ota_store.confirm()
                ota_state = "current"
                log_event("ota_confirmed", version=ota_version)
        else:
            ota_healthy_since = None
        if ota_store.state["trial"] and now - ota_trial_started > 300:
            ota_store.rollback()
            supervisor.reload()
        return
    if not online or hold.active(now) or now < ota_next_check:
        return
    import sys
    from gate_http import DeviceHTTP
    from gate_ota import validate_manifest

    def service():
        client.poll()
        service_outputs(runtime, online=bool(wifi.radio.connected))
        if watchdog_timer:
            watchdog_timer.feed()
        if hold.active(time.monotonic()):
            raise OSError("hold_active")

    try:
        if ota_http is None:
            if os.getenv("OTA_DEVICE_ID") != device_suffix().lower():
                raise ValueError("ota_identity_mismatch")
            ota_http = DeviceHTTP(
                adafruit_connection_manager.get_radio_socketpool(wifi.radio),
                device_suffix().lower(),
                os.getenv("OTA_TOKEN") or "",
            )
        response = ota_http.request(
            "manifest", service, lambda r: None if r.status == 204 else r.json()
        )
        if response is not None:
            manifest = validate_manifest(response, board.board_id, sys.implementation.version[0])
            if manifest["sequence"] > ota_store.state["floor"]:
                installed = ota_http.request(
                    "artifact?sequence=" + str(manifest["sequence"]),
                    service,
                    lambda r: (
                        ota_store.stage(manifest, r.chunks(), service) if r.status == 200 else False
                    ),
                    limit=manifest["size"],
                )
                if installed:
                    log_event("ota_staged", version=manifest["app_version"])
                    supervisor.reload()
        ota_http.request(
            "report",
            service,
            lambda r: None,
            body={
                "state": ota_state,
                "version": ota_version,
                "base_version": BASE_VERSION,
                "sequence": ota_selected["sequence"] if ota_selected else 0,
            },
        )
        ota_backoff = 60
        ota_next_check = time.monotonic() + 21600 + int.from_bytes(os.urandom(2), "big") % 1800
    except (OSError, ValueError, RuntimeError):
        log_event("ota_check_failed")  # URLs and credentials are deliberately omitted.
        ota_next_check = time.monotonic() + ota_backoff
        ota_backoff = min(ota_backoff * 2, 86400)


# TEMPORARY STARTUP DIAGNOSTIC — remove this function and its call in main()
# once the external wiring has been verified. It flashes the three candidate
# signal pins together before Wi-Fi, MQTT, or any other controller work starts.
def startup_pin_diagnostic():
    pins = [digitalio.DigitalInOut(pin) for pin in (board.D0, board.D1, board.D2)]
    try:
        for output in pins:
            output.switch_to_output(value=False)
        for _ in range(3):
            for output in pins:
                output.value = True
            time.sleep(0.2)
            for output in pins:
                output.value = False
            time.sleep(0.2)
    finally:
        for output in pins:
            output.value = False
            output.deinit()


def service_status_led(wifi_connected, mqtt_connected, gate_active, now):
    """Independent health, Wi-Fi, MQTT and hold LEDs; never touch D10 here."""
    global hold_samples_left
    tick = application.tick if application is not None else indicators.tick
    changed, elapsed = tick(now, wifi_connected, mqtt_connected, gate_active)
    led.value = not indicators.alive_on
    wifi_led.value = indicators.wifi_on
    mqtt_led.value = indicators.mqtt_on
    hold_led.value = indicators.hold_on
    if changed:
        hold_samples_left = 4
        log_event("indicator_mode", **indicator_status())
    if elapsed is not None and hold_samples_left:
        hold_samples_left -= 1
        log_event("indicator_edge", pin="D2", on=indicators.hold_on, elapsed_ms=elapsed)


def indicator_status():
    return {
        "wifi_connected": bool(indicators.wifi_connected),
        "mqtt_connected": bool(indicators.mqtt_connected),
        "wifi_led_on": wifi_led.value,
        "mqtt_led_on": mqtt_led.value,
        "alive_edge_count": indicators.alive_edges,
        "transistor_high": bool(gate_output.value),
        "onboard_led_on": not led.value,
        "hold_led_on": hold_led.value,
        "hold_edge_count": indicators.hold_edges,
    }


def device_suffix():
    return "".join("{:02X}".format(value) for value in microcontroller.cpu.uid[-3:])


def setup_ssid():
    """Derive an SSID that will not collide with another setup controller."""
    return "Gate-Setup-" + device_suffix()


def default_topic(message_kind):
    return "gate/v1/devices/{}/{}".format(device_suffix().lower(), message_kind)


def load_config():
    """Return saved configuration and migrate the earlier Wi-Fi-only record."""
    nvm = microcontroller.nvm
    magic = bytes(nvm[: len(CONFIG_MAGIC)])
    if magic == CONFIG_MAGIC:
        limit = CONFIG_SIZE
        start = len(CONFIG_MAGIC) + 2
        size = int.from_bytes(bytes(nvm[len(CONFIG_MAGIC) : start]), "big")
    elif magic in (OLD_CONFIG_MAGIC, b"GATE2"):
        limit = OLD_CONFIG_SIZE if magic == OLD_CONFIG_MAGIC else CONFIG_SIZE
        start = len(CONFIG_MAGIC) + 1
        size = nvm[len(CONFIG_MAGIC)]
    else:
        return None

    if size == 0 or size > limit - start:
        return None

    try:
        config = json.loads(bytes(nvm[start : start + size]).decode("utf-8"))
        if not isinstance(config, dict) or not config.get("ssid"):
            return None
        return config
    except (ValueError, UnicodeError):
        return None


def add_settings_credentials(config):
    """Use deploy-time MQTT credentials while keeping Wi-Fi in board NVM."""
    if not config:
        return None
    result = dict(config)
    username = os.getenv("MQTT_USERNAME")
    password = os.getenv("MQTT_PASSWORD")
    if username and password:
        result["mqtt_username"] = username
        result["mqtt_password"] = password
        result.setdefault("mqtt_topic", default_topic("status"))
        result.setdefault("mqtt_command_topic", default_topic("command"))
    return result


def save_config(config):
    """Store configuration outside CIRCUITPY so USB mounting cannot block writes."""
    payload = json.dumps(config).encode("utf-8")
    if len(payload) > CONFIG_SIZE - len(CONFIG_MAGIC) - 2:
        raise ValueError("Configuration is too long")

    record = bytearray(CONFIG_SIZE)
    record[: len(CONFIG_MAGIC)] = CONFIG_MAGIC
    start = len(CONFIG_MAGIC) + 2
    record[len(CONFIG_MAGIC) : start] = len(payload).to_bytes(2, "big")
    record[start : start + len(payload)] = payload
    microcontroller.nvm[:CONFIG_SIZE] = record


def url_decode(value):
    """Decode application/x-www-form-urlencoded text without an external lib."""
    decoded = bytearray()
    index = 0
    while index < len(value):
        character = value[index]
        if character == "+":
            decoded.append(32)
        elif character == "%" and index + 2 < len(value):
            try:
                decoded.append(int(value[index + 1 : index + 3], 16))
                index += 2
            except ValueError:
                decoded.extend(character.encode("utf-8"))
        else:
            decoded.extend(character.encode("utf-8"))
        index += 1
    return decoded.decode("utf-8")


def parse_form(body):
    fields = {}
    for item in body.decode("utf-8").split("&"):
        key, separator, value = item.partition("=")
        if separator:
            fields[url_decode(key)] = url_decode(value)
    return fields


def page(message=""):
    return """<!doctype html>
<html><head><meta name=\"viewport\" content=\"width=device-width,initial-scale=1\">
<title>Gate controller setup</title>
<style>body{{font:17px sans-serif;max-width:34rem;margin:3rem auto;padding:0 1rem}}input{{box-sizing:border-box;width:100%;padding:.7rem;margin:.3rem 0 1rem}}button{{padding:.7rem 1rem}}small{{display:block;margin-top:-.7rem;margin-bottom:1rem}}</style>
</head><body><h1>Gate controller setup</h1><p>{message}</p>
<form action=\"/configure\" method=\"post\"><h2>Wi-Fi</h2>
<label>Network name (SSID)</label><input name=\"ssid\" maxlength=\"32\" autofocus>
<small>Leave Wi-Fi fields blank to keep the saved network.</small>
<label>Wi-Fi password</label><input name=\"password\" type=\"password\" maxlength=\"63\">
<h2>EMQX MQTT</h2><p>Broker: <code>{broker}:{port}</code></p>
<label>MQTT username</label><input name=\"mqtt_username\" maxlength=\"96\" required>
<label>MQTT password</label><input name=\"mqtt_password\" type=\"password\" maxlength=\"128\" required>
<label>Status topic</label><input name=\"mqtt_topic\" maxlength=\"128\" value=\"{status_topic}\" required>
<small>The controller publishes retained status to this topic.</small>
<label>Command topic</label><input name=\"mqtt_command_topic\" maxlength=\"128\" value=\"{command_topic}\" required>
<small>Publish JSON blink commands here.</small>
<button type=\"submit\">Save and connect</button></form></body></html>""".format(
        message=message,
        broker=MQTT_BROKER,
        port=MQTT_PORT,
        status_topic=default_topic("status"),
        command_topic=default_topic("command"),
    )


def send_response(client, body, status="200 OK"):
    encoded_body = body.encode("utf-8")
    headers = (
        "HTTP/1.1 {}\r\nContent-Type: text/html; charset=utf-8\r\n"
        "Content-Length: {}\r\nConnection: close\r\nCache-Control: no-store\r\n\r\n"
    ).format(status, len(encoded_body))
    client.sendall(headers.encode("utf-8"))
    client.sendall(encoded_body)


def config_from_form(fields):
    previous = load_config() or {}
    submitted_ssid = fields.get("ssid", "").strip()
    submitted_password = fields.get("password", "")
    ssid = submitted_ssid or previous.get("ssid", "")
    password = (
        submitted_password
        if submitted_ssid and submitted_ssid != previous.get("ssid")
        else submitted_password or previous.get("password", "")
    )
    if not ssid:
        raise ValueError("Enter a Wi-Fi network name.")
    if password and not 8 <= len(password) <= 63:
        raise ValueError("Wi-Fi passwords must be 8 to 63 characters.")

    username = fields.get("mqtt_username", "").strip()
    mqtt_password = fields.get("mqtt_password", "")
    topic = fields.get("mqtt_topic", "").strip()
    command_topic = fields.get("mqtt_command_topic", "").strip()
    if not username or not mqtt_password:
        raise ValueError("Enter the MQTT username and password.")
    if not topic:
        raise ValueError("Enter an MQTT status topic.")
    if not command_topic:
        raise ValueError("Enter an MQTT command topic.")
    if topic == command_topic or any(c in topic + command_topic for c in "#+\x00"):
        raise ValueError("Use distinct MQTT topics without wildcards.")
    return {
        "ssid": ssid,
        "password": password,
        "mqtt_username": username,
        "mqtt_password": mqtt_password,
        "mqtt_topic": topic,
        "mqtt_command_topic": command_topic,
    }


def read_http_request(client):
    """Read bounded headers and the entire body, including fragmented POSTs."""
    request = bytearray()
    buffer = bytearray(512)
    while b"\r\n\r\n" not in request:
        received = client.recv_into(buffer)
        if not received:
            raise ValueError("incomplete HTTP headers")
        request.extend(buffer[:received])
        if len(request) > 4096:
            raise ValueError("HTTP headers too large")
    header, _, body = bytes(request).partition(b"\r\n\r\n")
    length = 0
    for line in header.split(b"\r\n")[1:]:
        key, _, value = line.partition(b":")
        if key.lower() == b"content-length":
            length = int(value.strip())
        if key.lower() == b"transfer-encoding":
            raise ValueError("unsupported transfer encoding")
    if not 0 <= length <= 4096:
        raise ValueError("HTTP body too large")
    while len(body) < length:
        received = client.recv_into(buffer)
        if not received:
            raise ValueError("incomplete HTTP body")
        body += bytes(buffer[:received])
    return header, body[:length]


def service_http(server):
    """Process one configuration request, if a browser has made one."""
    try:
        client, _ = server.accept()
    except OSError:
        return

    try:
        client.settimeout(1)
        header, body = read_http_request(client)
        request_line = header.split(b"\r\n", 1)[0].split(b" ")

        if (
            len(request_line) >= 2
            and request_line[0] == b"POST"
            and request_line[1] == b"/configure"
        ):
            save_config(config_from_form(parse_form(body)))
            send_response(
                client, page("Saved. The controller is restarting and will connect securely.")
            )
            time.sleep(1)
            supervisor.reload()
        else:
            send_response(client, page())
    except (OSError, UnicodeError, ValueError):
        try:
            send_response(client, page("Please check the fields and try again."), "400 Bad Request")
        except OSError:
            pass
    finally:
        client.close()


def service_dns(dns_socket, ap_ip):
    """Resolve DNS requests to the setup page for captive-portal behavior."""
    packet = bytearray(256)
    try:
        size, client_address = dns_socket.recvfrom_into(packet)
    except OSError:
        return

    query = bytes(packet[:size])
    if len(query) < 17:
        return
    end = 12
    while end < len(query) and query[end] != 0:
        label_size = query[end]
        if label_size & 0xC0:
            return
        end += label_size + 1
    if end + 5 > len(query):
        return

    question = query[12 : end + 5]
    address_bytes = bytes(int(part) for part in ap_ip.split("."))
    response = (
        query[:2]
        + b"\x81\x80"
        + query[4:6]
        + b"\x00\x01\x00\x00\x00\x00"
        + question
        + b"\xc0\x0c\x00\x01\x00\x01\x00\x00\x00\x1e\x00\x04"
        + address_bytes
    )
    try:
        dns_socket.sendto(response, client_address)
    except OSError:
        pass


def mqtt_ready(config):
    return bool(
        config
        and config.get("mqtt_username")
        and config.get("mqtt_password")
        and config.get("mqtt_topic")
        and config.get("mqtt_command_topic")
    )


def log_event(event, **fields):
    fields.update(event=event, boot_id=BOOT_ID, uptime_ms=int(time.monotonic() * 1000))
    print("GATE_LOG " + json.dumps(fields))


def status_payload(runtime):
    return json.dumps(
        {
            "version": 1,
            "type": "device_status",
            "state": "online",
            "device_id": device_suffix().lower(),
            "ip": str(wifi.radio.ipv4_address),
            "boot_id": BOOT_ID,
            "uptime_ms": int(time.monotonic() * 1000),
            "indicators": indicator_status(),
            "hold_remaining_seconds": hold.remaining(time.monotonic()),
            "firmware": {
                "version": ota_version,
                "bootstrap": BASE_VERSION,
                "base_version": BASE_VERSION,
                "state": ota_state,
            },
        }
    )


def on_mqtt_message(client, topic, message):
    runtime = client.user_data
    if topic != runtime["command_topic"]:
        return
    if getattr(client, "message_retained", False):
        log_event("command_rejected", reason="retained hold commands are unsafe")
        return
    try:
        (application or create_app(Platform(), time.monotonic())).on_message(
            message, False, time.monotonic()
        )
    except ValueError:
        log_event("command_rejected", reason="invalid hold schema")
        return
    client.user_data["dirty"] = True
    log_event("hold_applied", command_id=hold.command_id, duration_seconds=hold.duration_seconds)


def service_outputs(runtime, online):
    now = time.monotonic()
    active = hold.active(now)
    gate_output.value = active
    service_status_led(bool(wifi.radio.connected), online, active, now)
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

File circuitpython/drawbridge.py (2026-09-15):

"""OTA application: command policy and independent status indicator schedules.

The USB bootstrap owns pins, TLS, output deadlines, and update storage.
This interface is a coding boundary, not a Python security sandbox.
"""

import json

APP_VERSION = "1.0.1"
APP_API_VERSION = 1


class Indicators:
    def __init__(self, now):
        self.wifi_connected = None
        self.mqtt_connected = None
        self.holding = None
        self.alive_on = True
        self.alive_epoch = now
        self.alive_edges = 0
        self.wifi_on = False
        self.mqtt_on = False
        self.hold_on = False
        self.wifi_epoch = now
        self.mqtt_epoch = now
        self.hold_edge = now
        self.hold_edges = 0

    def tick(self, now, wifi_connected, mqtt_connected, holding):
        mqtt_connected = bool(wifi_connected and mqtt_connected)
        changed = (
            wifi_connected != self.wifi_connected
            or mqtt_connected != self.mqtt_connected
            or holding != self.holding
        )
        # Two 100 ms flashes identify firmware 1.0.1 without blocking the loop.
        alive_phase = (now - self.alive_epoch) % 2
        alive_on = alive_phase < 0.1 or 0.25 <= alive_phase < 0.35
        if alive_on != self.alive_on:
            self.alive_edges += 1
        self.alive_on = alive_on
        if wifi_connected != self.wifi_connected:
            self.wifi_epoch = now
            self.mqtt_epoch = now
        if mqtt_connected != self.mqtt_connected:
            self.mqtt_epoch = now
        self.wifi_connected = wifi_connected
        self.mqtt_connected = mqtt_connected
        self.wifi_on = wifi_connected or (now - self.wifi_epoch) % 1 < 0.5
        self.mqtt_on = wifi_connected and (mqtt_connected or (now - self.mqtt_epoch) % 1 < 0.5)

        elapsed = None
        if holding != self.holding:
            self.holding = holding
            self.hold_on = holding
            self.hold_edge = now
        elif holding and now - self.hold_edge >= 0.125:
            elapsed = round((now - self.hold_edge) * 1000, 1)
            self.hold_on = not self.hold_on
            self.hold_edge = now
            self.hold_edges += 1
        return changed, elapsed


class App:
    def __init__(self, platform, now):
        self.platform = platform
        self.indicators = Indicators(now)

    def on_message(self, message, retained, now):
        if retained:
            raise ValueError("retained hold commands are unsafe")
        value = json.loads(message)
        if (
            type(value) is not dict
            or type(value.get("version")) is not int
            or value.get("version") != 1
            or value.get("type") != "hold_gate"
        ):
            raise ValueError("invalid hold schema")
        self.platform.request_hold(value.get("duration_seconds"), value.get("command_id"), now)

    def tick(self, now, wifi_connected, mqtt_connected, holding):
        return self.indicators.tick(now, wifi_connected, mqtt_connected, holding)


def create_app(platform, now):
    return App(platform, now)

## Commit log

2023-03-27 Using more accurate constant name for pin.
2023-03-27 Changing semantics to more closely match the use-case.
2026-06-18 Add KiCad FeatherWing PCB template for gate controller board
    [gate-controller.kicad_pcb, gate-controller.sch]
2026-06-18 Add FeatherWing gate controller PCB design spec
2026-06-18 Add FeatherWing PCB implementation plan
2026-06-18 Add gate controller circuit components to schematic
    [gate-controller.sch]
2026-06-18 Add .gitignore for KiCad temp files
2026-06-18 Update README with hardware docs and BOM
2026-09-10 Add tested XIAO MQTT CircuitPython workflow
2026-09-12 Add timed MQTT gate hold and mini breadboard layout
    [gate-controller.kicad_pcb, gate-controller.kicad_sch, gate-controller.sch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]
2026-09-13 Add four-state CircuitPython indicators
2026-09-13 Add per-device hold metrics
2026-09-13 Document installed gate wiring
2026-09-13 Add Drawbridge loader and FeatherWing fabrication release
    [bom.csv, drawbridge-featherwing.kicad_pcb, drawbridge-featherwing.kicad_sch]
2026-09-13 Finalize FeatherWing fabrication design
    [bom.csv, drawbridge-featherwing.kicad_pcb, drawbridge-featherwing.kicad_sch]
2026-09-14 Use a screw terminal and 45-degree routing on the FeatherWing
    [bom.csv, drawbridge-featherwing.kicad_pcb, drawbridge-featherwing.kicad_sch]
2026-09-15 Make 5% resistor tolerance explicit in assembly BOM
    [bom.csv]
